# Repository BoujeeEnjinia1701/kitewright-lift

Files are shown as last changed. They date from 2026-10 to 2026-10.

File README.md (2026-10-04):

# Kitewright Lift

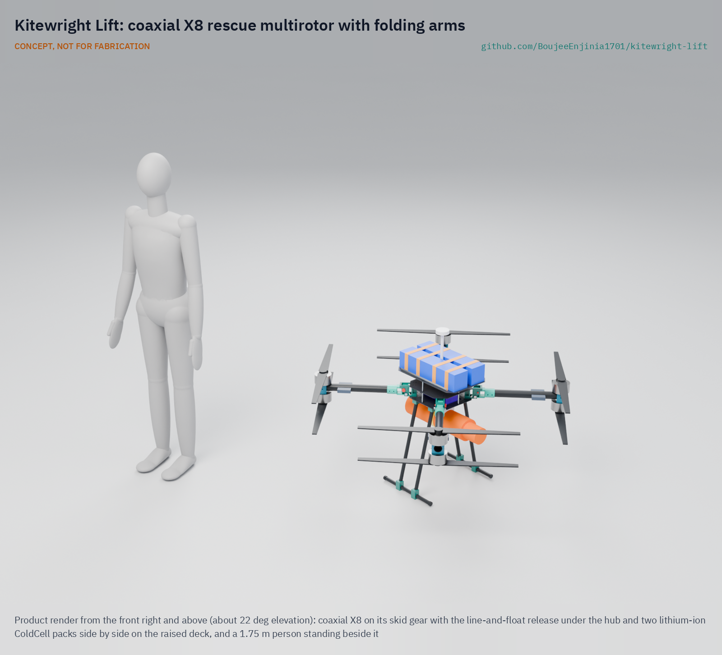
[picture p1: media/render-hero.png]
Kitewright Lift: coaxial X8 rescue multirotor with folding arms


     

**Area:** Aerial robotics · **TRL:** 3 of 9 (proof of concept on paper; design constructable) · **Value-engineering target:** USD 5,000; estimated cost of the constructable design USD 6,627 (USD 1,627 over the target) · **Difficulty:** 4 of 5

[Design precis](docs/02-concept.md) · [Requirements](docs/03-requirements.md) · [Calculations](docs/04-calcs/01-sizing.md) · [Prototype build plan](docs/05-build-plan.md) · [Design decisions](docs/06-design-decisions.md) · [General arrangement](cad/drawings/KWL-DWG-001.pdf) · [3D viewer](media/viewer.html)

A multirotor frame for the Kitewright family that hovers, lifts, winches and flies on a tether in disasters and remote terrain.

## Concept rationale

Kitewright Lift is the utility multirotor of the Kitewright family. It is a frame, motors and propellers built around the shared Kitewright Core, so the autopilot, ColdCell power bus and payload mount are the same as on every other Kitewright aircraft. What Lift adds is lift: enough thrust margin to hover with a few kilograms at altitude, a clear space under the body for payloads, and a power input for a ground tether. The same frame can search, drop a line or float, lower a small load, or stay up for hours as a lookout or radio relay over a disaster site.

The frame is sized for thin air from the start, because the family's first target is the high mountains of Kashmir and the Himalaya. Our first estimate is that at 5,000 m and -20 °C hover time falls to about 47% of sea level (estimate), so propeller and motor choices come from AltiRig bench data rather than sea-level catalogues. Keeping the take-off mass at or under 25 kg keeps Lift in the small drone classes used by the FAA and by India's Drone Rules 2021.

## Burning platform

Floods and landslides regularly cut people off. The 2022 Pakistan floods affected 33 million people ([UN News, 2022](https://news.un.org/en/story/2022/08/1125752)); the 2024 eastern Bangladesh floods affected 5.6 million, with more than 500,000 seeking shelter ([UNICEF, 2024](https://www.unicef.org/press-releases/two-million-children-risk-worst-floods-three-decades-lash-through-eastern-bangladesh)). The October 2023 South Lhonak glacial lake outburst in Sikkim left at least 35 dead and about 104 missing, destroyed 13 bridges and affected more than 60,000 people ([Mongabay India, 2023](http://india.mongabay.com/2023/10/no-early-warning-system-and-insufficient-dam-safety-turned-sikkim-flood-deadly/)). In events like these, drones already help: DJI counts more than 1,000 people rescued with drone help worldwide ([DJI, 2023](https://www.dji.com/media-center/announcements/dji-records-more-than-1000-people-rescued-by-drones-globally)).

Heavy-lift capability exists, but closed and costly. The DJI FlyCart 30 carries 30 kg with two batteries, has a winch mode for places it cannot land and a 6,000 m service ceiling ([Wikipedia, DJI FlyCart](https://en.wikipedia.org/wiki/DJI_FlyCart)); on Everest it carried 15 kg between 5,300 and 6,000 m ([DJI, 2024](https://www.dji.com/media-center/announcements/dji-completes-world-first-drone-delivery-tests-on-mount-everest-en)). The smaller DJI Matrice 350 RTK costs USD 14,814 for a 960 g payload ([Advexure](https://advexure.com/products/dji-matrice-350-rtk)). There is no open multirotor frame, documented for altitude and cold, that rescue groups can build, repair and fit with their own payloads.

## Where it could be used

### By industry

| Industry | Use |
| --- | --- |
| Flood and disaster response | Hover over stranded people, drop a float or line, and relay radio from a tether |
| Mountain rescue | Search with AvalancheScout and thermal payloads; lower small items to a casualty |
| Glacial hazard monitoring | Short-range lake and moraine survey with LakeWatch where Range cannot land |
| Remote health and logistics | Carrying light medical supplies across cut roads and rivers |
| Infrastructure inspection | Bridges, dams and hydropower intakes in steep valleys |
| Research and education | An open multirotor test bed for payload and high-altitude flight work |

### By country or region

| Country or region | Why it matters there |
| --- | --- |
| India (Sikkim and the Himalaya) | The 2023 South Lhonak outburst destroyed 13 bridges and affected more than 60,000 people ([Mongabay India, 2023](http://india.mongabay.com/2023/10/no-early-warning-system-and-insufficient-dam-safety-turned-sikkim-flood-deadly/)); a Lift at or under 25 kg sits in the Small class of India's Drone Rules 2021 ([PIB](https://static.pib.gov.in/writereaddata/specificdocs/documents/2022/jan/doc202212810701.pdf)). |
| Pakistan | The 2022 floods affected 33 million people and damaged about 3,500 km of roads and 150 bridges ([UN News, 2022](https://news.un.org/en/story/2022/08/1125752)); in the Karakoram a drone found Rick Allen alive on Broad Peak ([Explorersweb, 2018](https://explorersweb.com/rick-allen-found-alive-on-broad-peak/)). |
| Bangladesh | The 2024 eastern floods affected 5.6 million people with more than 500,000 in shelters ([UNICEF, 2024](https://www.unicef.org/press-releases/two-million-children-risk-worst-floods-three-decades-lash-through-eastern-bangladesh)). |
| Nepal | Drone delivery on Everest replaced 6 to 8 hour icefall carries with a 12 minute round trip in 2024 tests ([DJI, 2024](https://www.dji.com/media-center/announcements/dji-completes-world-first-drone-delivery-tests-on-mount-everest-en)). |
| United States | Part 107 covers drones under 55 lb (25 kg) and allows securely attached external loads ([FAA](https://www.faa.gov/uas/media/Part_107_Summary.pdf)), which is the class Lift targets. |

## What sparked the idea

In July 2018 the climber Rick Allen went missing high on Broad Peak in the Karakoram after a fall while descending. After 36 hours, Bartek Bargiel, who was filming a ski descent of K2, flew a small drone over the slope, spotted Allen alive at about 7,500 m and guided climbers to him ([Explorersweb, 2018](https://explorersweb.com/rick-allen-found-alive-on-broad-peak/)). The drone was a DJI Mavic Pro, flown far above its rated ceiling ([DroneDJ, 2018](https://dronedj.com/2018/07/16/mountaineer-rick-allen-was-feared-dead-on-broad-peak-but-a-dji-mavic-pro-drone-found-him-alive/)). Kitewright Lift is the frame that could follow such a find: hover over the spot, lower a line or supplies, and stay overhead while the rescuers climb.

## Problem

After floods, landslides and mountain accidents, rescuers need a drone that can hover over one spot, carry a few kilograms, lower a line or a float, and stay up for hours on a tether. Drones that do this are closed and cost many times what local teams can spend.

Full problem statement: [docs/01-problem.md](docs/01-problem.md)

## Concept

A coaxial X8 for the Kitewright family: four carbon arms that fold down on machined hinges, a motor above and below each arm tip with 30 inch propellers, the Kitewright Core hung under a two-plate carbon hub to the family envelope, two ColdCell packs on a raised deck above, and payloads on the Core's rail below. Lift holds each arm up against a fixed stop in flight, so a missed lock pin cannot let an arm fold. Two payloads are designed with it: a line-and-float release and a 400 V tether module for hours of hover.

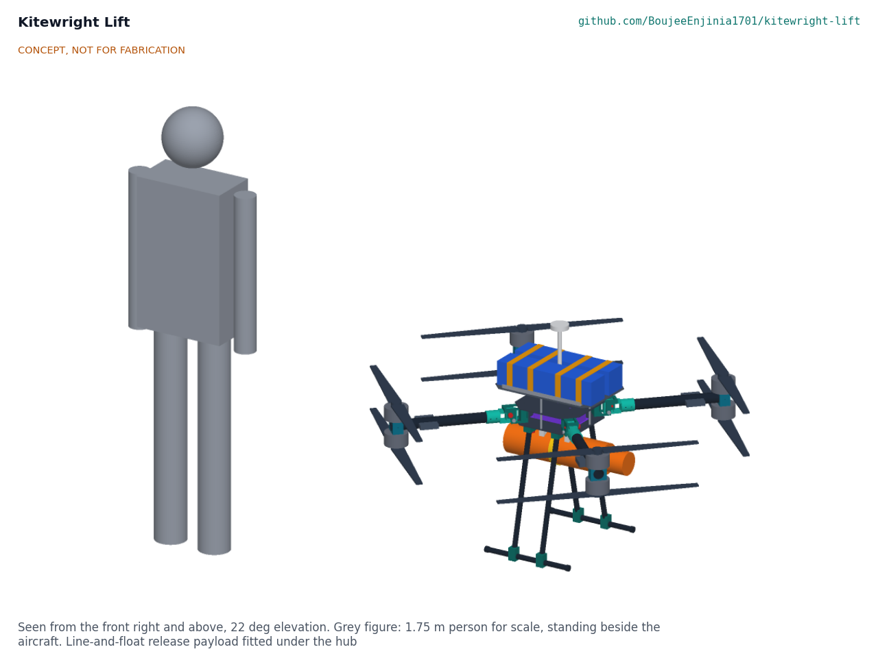
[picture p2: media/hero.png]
Kitewright Lift concept with a 1.75 m person for scale


Full design precis: [docs/02-concept.md](docs/02-concept.md) · Requirements: [docs/03-requirements.md](docs/03-requirements.md)

## Key numbers (KWL-CAL-001, estimates)

| Quantity | Value |
| --- | --- |
| Take-off mass | 21.8 kg ready to fly; 25.0 kg with the rated 3.2 kg payload |
| Thrust to weight | 2.88 at sea level; 1.84 at 5,000 m and -20 °C with 2 kg; 1.43 there with a motor out |
| Hover time (two ColdCell lithium-ion packs, 1,361 Wh) | 20.4 min at sea level with the rated payload; 14.5 min at 5,000 m with 2 kg |
| Tethered hover | 3.6 kW from a 400 V ground supply over 60 m of tether |
| Folded | 0.88 x 0.48 x 0.45 m, gear on |

No decisions are open: R4's sea-level case now reads "with the rated payload" (2026-10-04); see the [design decisions register](docs/06-design-decisions.md).

## Key components

- Carbon hub plates and battery deck
- Machined arm hinges with stop bridge, pivot bolt and lock pin
- Carbon arm tubes, root fittings and coaxial motor clamps
- Eight motors, controllers and 30 inch folding propellers
- Kitewright Core, hung under the hub to the family envelope
- Two ColdCell packs
- Skid landing gear
- Line-and-float release payload
- Tether module and ground set
- Winch module (not designed until its patent screen)

## Building the prototype

The [prototype build plan](docs/05-build-plan.md) (KWL-BLD-001) takes a capable maker through every component in build order, with a making sketch for each made part, close-ups of the joints and a picture for every assembly step. The carbon plates are CNC routed, the carbon tubes cut and drilled, and the aluminium hinge, arm and gear fittings machined; the Core and packs are built to their own designs. The hinges are proof-loaded before first flight, and the plan's safety stops cover first power, first flight, the tether and payload drops. It is a plan, not yet built.

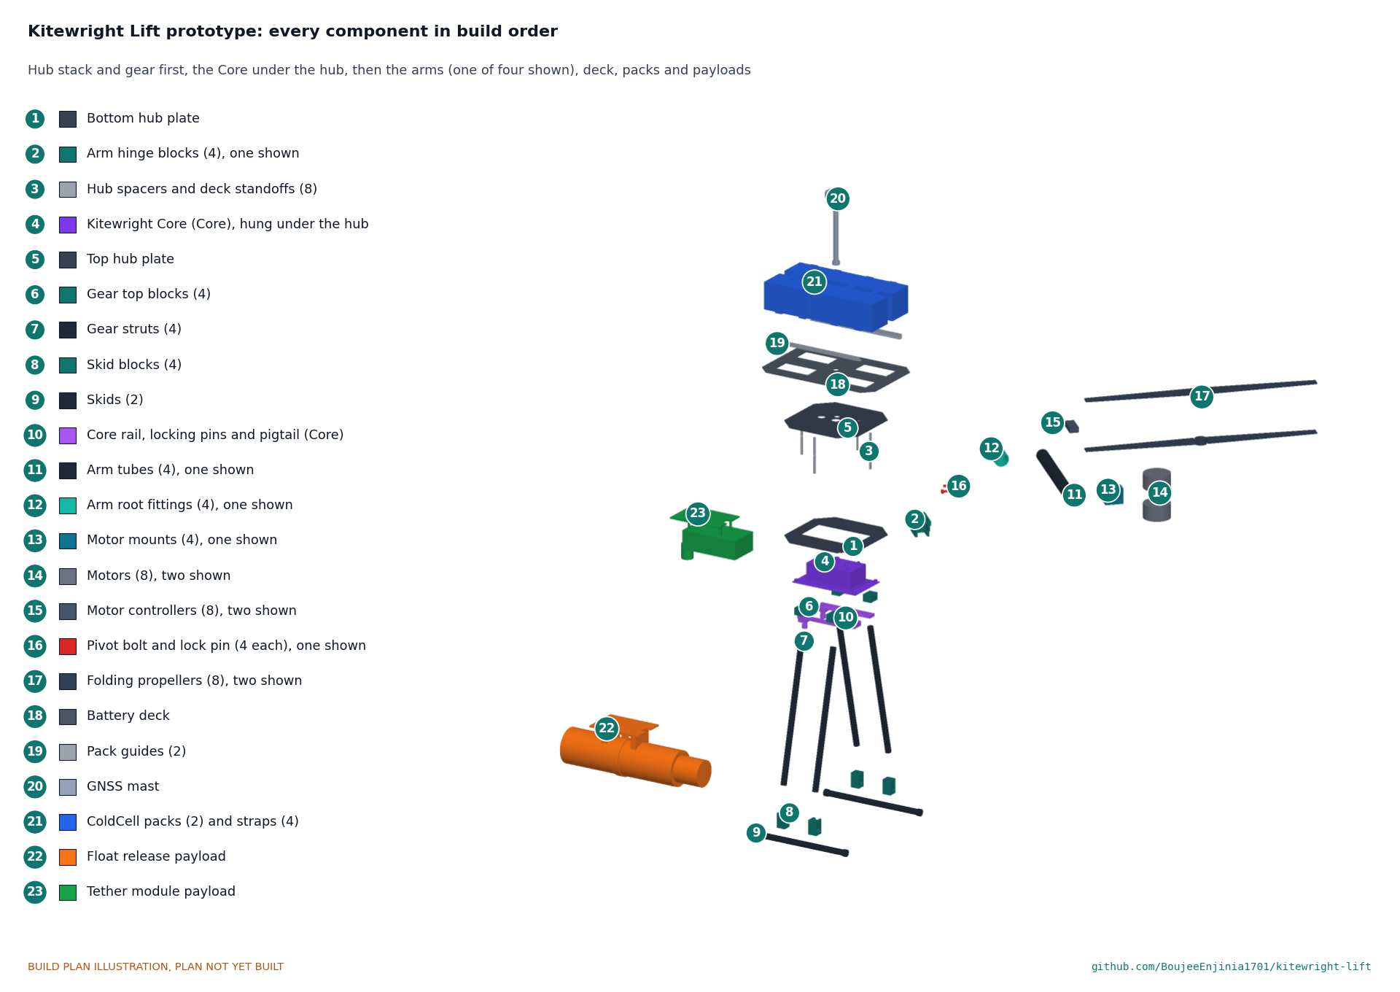
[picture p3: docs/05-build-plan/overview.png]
Every component in build order


## Safety

> Published as an open engineering reference, not certified aviation equipment.
>
> Civilian use only. No weapons, targeting or military payloads, and none will be accepted into the family.
>
> Certification and operating approvals (FAA Part 107 in the United States, EASA rules in Europe, India's DGCA Drone Rules 2021) are out of scope at this TRL and will be addressed if prototypes progress. Builders must fly only where local rules allow.
>
> Propellers can cause serious injury: arm only with every arm lock pin in and flagged and nobody within 15 m, and write pre-flight, arming and keep-out procedures before any powered test. Every arm hinge is proof-loaded before first flight.
>
> The tether carries 400 V DC: isolated, monitored ground supply with an emergency stop; nobody handles a live tether.
>
> Lithium battery packs can catch fire after a crash, over-charge or cold charging; follow ColdCell safety rules.
>
> Never carry or lift people. Suspended loads and lines must have a release that the pilot can operate at any time, and nobody stands under a suspended load. The float's line is never tied to the aircraft; drops are made from 10 m or higher.
>
> A tether can snag or conduct: route it clear of people, power lines and water currents, and fit a breakaway at the aircraft.
>
> Downwash near people in water, on snow slopes or on rooftops can knock them over or trigger slides; keep a minimum hover height set by test.
>
> Loss of link or thrust in thin air can mean a crash in remote terrain; failsafes must be set and tested at each altitude band.
>
> This design is published as an open engineering reference. It is not certified equipment. CONCEPT, NOT FOR FABRICATION.

## Repository layout

| Folder | Contents |
| --- | --- |
| `docs/` | Problem, concept, requirements, calculations and design decisions |
| `cad/src/` | build123d Python source, the source of truth for all geometry |
| `cad/step/`, `cad/stl/` | Exported models for FreeCAD, other CAD tools and printing |
| `cad/drawings/` | 2D sketches and dimensioned drawings |
| `bom/` | Bill of materials |
| `electronics/` | KiCad schematics and PCB layouts |
| `firmware/` | Microcontroller code |
| `media/` | Renders, perspectives and photos |
| `build-log/` | Dated prototyping notes |

## Documentation

Controlled documents follow the portfolio [documentation standard](.kit/STANDARDS.md). Each carries a document ID (KWL-PRC-001 for the precis), a version and a revision history. Branded PDFs are built with `python .kit/render.py` and attached to GitHub Releases when a document is tagged, for example `KWL-PRC-001/v1.0`.

## Credits

Designed by Amish Chadha at Design Molecule Labs. See [CONTRIBUTORS.md](CONTRIBUTORS.md) for roles. To cite this design, use [CITATION.cff](CITATION.cff) (GitHub shows it as "Cite this repository").

AI assistance (Claude) was used to accelerate prototype documentation and first-pass research. Design direction and all decisions are Amish Chadha's, recorded in this repository's decision records (`docs/decisions/`).

## Licenses

- **Hardware** (CAD, drawings, BOM, electronics): [CERN-OHL-S v2](LICENSE)
- **Software** (firmware, scripts, notebooks): [MIT](LICENSE-SOFTWARE)

A project of the [Design Molecule](https://designmolecule.com) lab.

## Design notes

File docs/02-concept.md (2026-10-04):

---
doc_id: KWL-PRC-001
title: Kitewright Lift design precis
project: Kitewright Lift
doc_type: Precis
version: "0.4"
status: Draft
date: '2026-10-04'
author: Amish Chadha
license: CERN-OHL-S-2.0
revisions:
- version: "0.1"
  date: '2026-09-30'
  author: Amish Chadha
  change: Initial scaffold
- version: "0.2"
  date: '2026-10-03'
  author: Amish Chadha
  change: TRL 2 and 3; coaxial X8 with down-folding arms (KWL-DDR-001), constructable design (KWL-DDR-002), first-order numbers from KWL-CAL-001, safety section
- version: "0.3"
  date: '2026-10-03'
  author: Amish Chadha
  change: Amish's decisions 34A and 35A (KWL-DDR-003); lighter fittings, lithium-ion ColdCell packs, frame-to-Core leads; numbers from KWL-CAL-001 v0.2
- version: "0.4"
  date: '2026-10-04'
  author: Amish Chadha
  change: Amish's round-3 decisions 8A, 9A and 10A (KWL-DDR-004); ColdCell's packs as drawn on a raised deck, the Core to the family envelope, payload shoes, rated payload 3.2 kg; numbers from KWL-CAL-001 v0.3
---

# Kitewright Lift design precis

A multirotor frame for the Kitewright family that hovers, lifts, winches and flies on a tether in disasters and remote terrain.

Kitewright Lift with the line-and-float release payload, a 1.75 m person for scale

*Figure 1. Kitewright Lift, flying-ready with the line-and-float release under the hub. CONCEPT, NOT FOR FABRICATION.*

## How it works

Kitewright Lift is a coaxial X8: four carbon arms on a two-plate carbon hub, each arm carrying one motor on top of its tip and one underneath, with 30 inch folding propellers turning opposite ways. If any one motor stops, its partner on the same arm keeps that corner flying, and the autopilot shares the load among the other arms, so the aircraft can still hover and land.

Each arm hinges on a machined aluminium block at a hub corner and folds down for transport. In flight the lift on the arm presses the arm's root fitting up against a stop bridge on the hinge block, so the arm cannot fold under power even if its lock pin were left out; the ball-lock pin only stops the arm drooping on the ground. Folded, with the propeller blades turned back along the arms, the aircraft measures about 0.88 x 0.48 x 0.45 m and fits the 1.2 x 0.6 x 0.5 m case of R9 with its landing gear on.

The Kitewright Core (autopilot, radios, power bus) hangs under the bottom hub plate to the family mounting envelope, its lid standing up through an opening into the hub. Two ColdCell packs, 410 x 94 x 94 mm and 4.46 kg each, sit side by side on a carbon deck raised above the upper rotors, held by guides and cam straps, with the GNSS mast between them. Under the Core, any Kitewright payload slides onto the Core's rail on its own payload shoe until it meets the front stops, two locking pins drop into the shoe, and the Core's DS-014 pigtail is plugged into the payload. Two payloads are designed here: the line-and-float release, which drops a foam float with 30 m of floating line to a person in water, and the tether module, which turns 400 V DC from a ground supply into the 51 V bus for hours of hover as a lookout or radio relay.

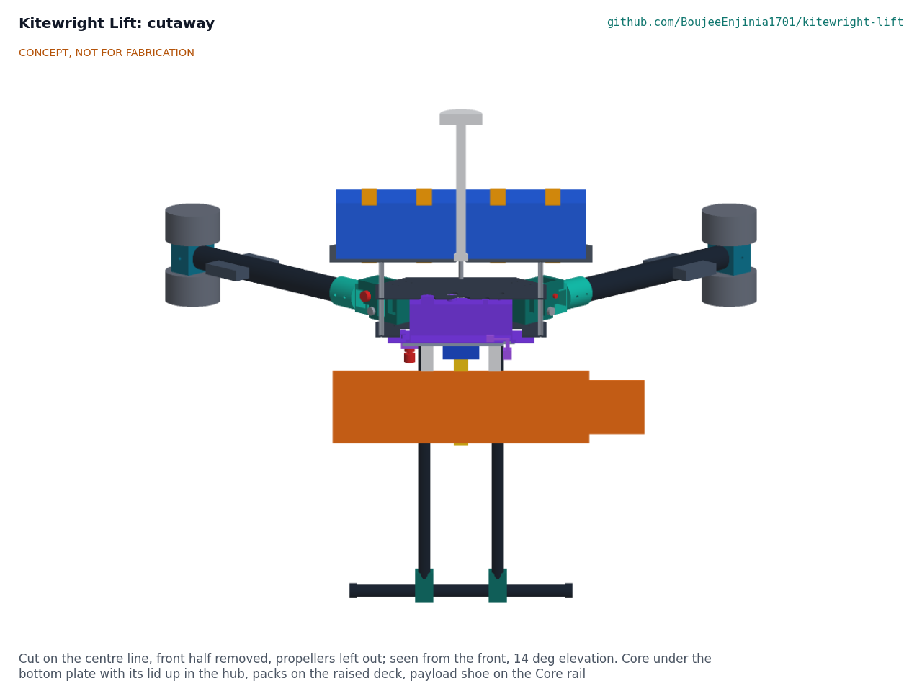
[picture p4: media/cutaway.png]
Cutaway of Kitewright Lift


*Figure 2. Cutaway on the centre line: the Core under the bottom plate with its lid up in the hub, the packs on the raised deck, the payload shoe on the Core's rail.*

## Components

| # | Component | Role |
| --- | --- | --- |
| 1 | Hub plates and spacers | Two 3 mm carbon plates 280 mm square, 60 mm apart, on the four hinge blocks and four spacers |
| 2 | Arm hinges | Machined clevis blocks with stop bridge, 8 mm pivot bolt and ball-lock pin; arms fold down |
| 3 | Arms | 40 mm carbon tubes bonded and bolted into aluminium root fittings and motor clamps |
| 4 | Motors, controllers and propellers | Eight motors of the 10 kg static thrust class, 80 A controllers on the arms, 30 x 10 folding propellers |
| 5 | Kitewright Core | Autopilot, GNSS, radios and the power bus with a tether input, unchanged from the Core design; hung under the hub to the family envelope |
| 6 | Battery deck and ColdCell packs | Two 14S3P lithium-ion heated packs (ColdCell variant for Lift) on a carbon deck above the hub, with Lift's own leads to the Core |
| 7 | Payload rail | The Core's rail, two locking pins and DS-014 pigtail under the Core plate |
| 8 | Line-and-float release | Fail-closed servo pin release, webbing sling, foam float with 30 m of line |
| 9 | Tether module and ground set | 4 kW onboard converter and breakaway; 400 V ground supply, 60 m tether, reel, insulation monitor and emergency stop |
| 10 | Landing gear | Four carbon struts and two skids, 450 mm apart, in machined blocks |
| 11 | Winch module | Not designed until its patent screen is done; the payload bay leaves room for it |

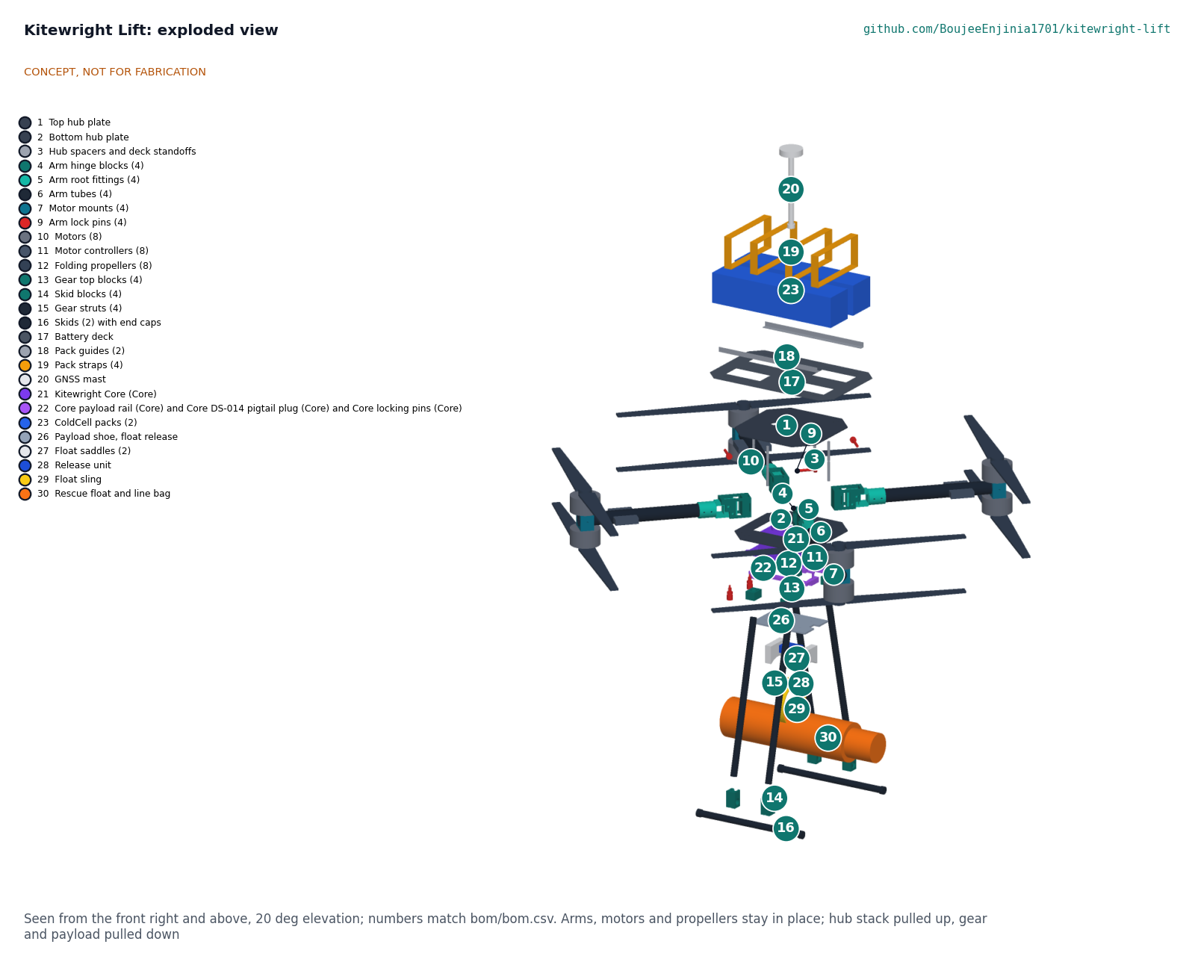
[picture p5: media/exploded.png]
Exploded view of Kitewright Lift


*Figure 3. Exploded view; numbers match `bom/bom.csv`.*

## Key design choices

All decided on 2026-10-03 under Amish's pre-approvals (KWL-DDR-001 and KWL-DDR-002):

- **Coaxial X8** rather than a flat hexa- or octocopter, for motor-out tolerance and a compact fold.
- **Arms fold down against a stop.** Lift holds each arm against a fixed bridge; the lock pin never carries flight loads.
- **Controllers on the arms**, so only two power leads per arm cross the hinge.
- **Fixed skid gear** that stays on when folded; the folded motors clear the skids and the ground.
- **One payload shoe** for every payload, to the Core's drawing KWC-DWG-106, inside the Core's 88 mm payload neck.
- **Fixed-voltage tether** (400 V DC) with an isolated onboard converter and a breakaway, clear of adaptive-voltage tether patents.
- **No winch** until its patent screen is done.

## First-order numbers

From KWL-CAL-001 (`docs/04-calcs/sizing.py`). All are estimates; nothing has been measured.

*Table 1. First-order numbers.*

| Quantity | Value | Assumptions |
| --- | --- | --- |
| Motor spacing; propellers | 1,240 mm diagonal; 30 inch, 115 mm tip gap, 170 mm coaxial gap | `cad/src/model.py` |
| Empty mass (no packs, no payload) | 12.9 kg | Made parts 5.08 kg from the model; motors 450 g, controllers 110 g, propellers 110 g, Core 0.99 kg, frame-to-Core leads 0.12 kg |
| Two ColdCell packs | 8.92 kg, 1,361 Wh | ColdCell's 14S3P lithium-ion pack as drawn, 410 x 94 x 94 mm, 4.46 kg each |
| Take-off mass with the rated payload | 24.98 kg with 3.2 kg (R1 limit 25 kg) | 21.78 kg ready to fly; float release 1.46 kg, tether module 3.13 kg |
| Hover power, sea level, rated payload | 3.2 kW | Coaxial factor 1.28, figure of merit 0.65, drive efficiency 0.80, 50 W avionics and payload |
| Hover time, sea level, rated payload | 20.4 min | 80 % of pack energy used |
| Hover time, 5,000 m and -20 C, 2 kg | 14.5 min | Air density 0.743 kg/m3; ColdCell delivers 85 % in the cold |
| Thrust to weight | 2.88 at sea level; 1.84 at 5,000 m | 10 kg per motor at full throttle, lower rotor 80 % |
| One motor out | 2.24 at sea level; 1.43 at 5,000 m | Partner motor alone on the failed arm |
| Arm load at full thrust | 177 N; 2.6 kN on the stop bridge | 30 mm from pivot to bridge |
| Tethered hover | 3.2 kW on the bus; 3.6 kW from the ground; 25 V drop and 225 W lost in the tether | 400 V, 60 m, 2 x 0.75 mm2, 95 % converter |
| Float drop | Expected miss 2.2 m from 10 m in 10 m/s wind | 2 m position hold; drift aimed off to 30 % |
| Folded size | 0.88 x 0.48 x 0.45 m | From the folded model |
| Warm-weather limit | Full hover flights to about 27 °C ambient | ColdCell's 50 °C warning, kept until measured (decision 9A) |
| Estimated cost | USD 6,627 for the aircraft; USD 3,976 for the payloads and ground equipment | `bom/bom.csv`, indicative prices |

Value-engineering target: USD 5,000. Estimated cost of the constructable design: USD 6,627 (USD 1,627 over the target).

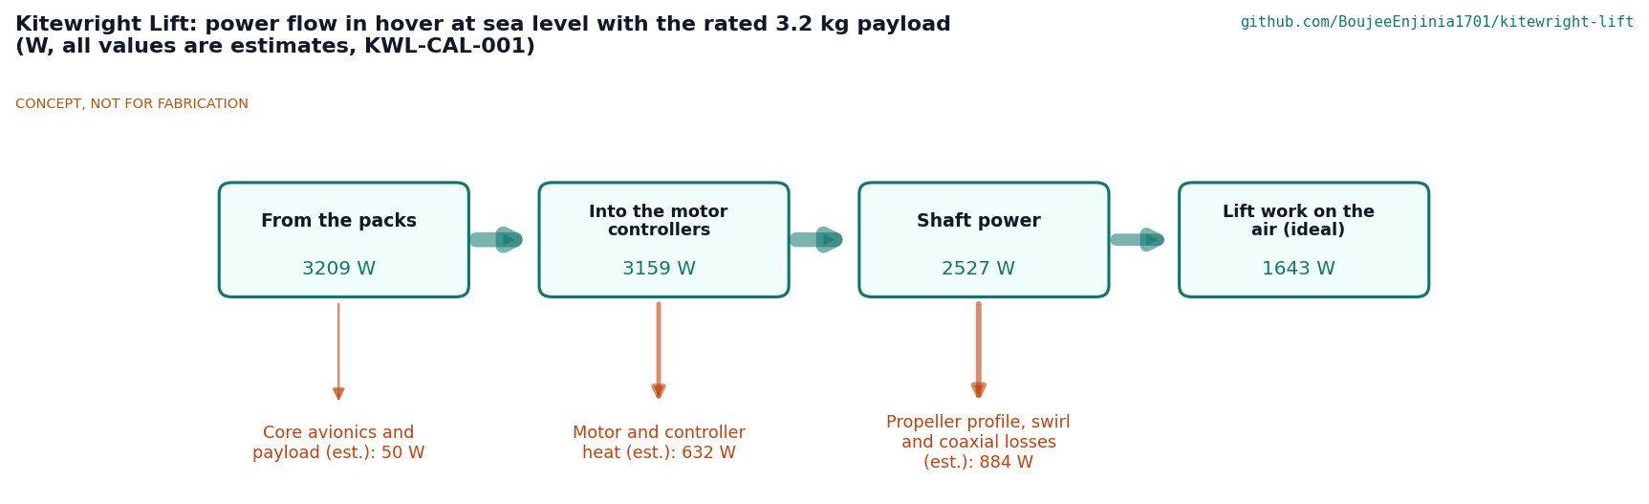
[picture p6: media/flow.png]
Power flow in hover


*Figure 4. Where the power goes in hover at sea level with 5 kg (estimates).*

## Patent design-arounds

From the preliminary patent, trademark and prior-art screen (not legal advice):

- Generic multirotor frame; no specific frame patents identified in the preliminary screen. The coaxial X8 layout and a clevis fold hinge are long-established.
- Winch not yet screened: no winch design is published until a patent screen is done.
- Tether power is a fixed-voltage supply with onboard DC-DC, not adaptive tether voltage (Elistair US11059580B2, to 2037).
- Payload mount and power bus follow the Kitewright Core design-arounds (DS-014 connector with plain rail and locking pin; external-heater ColdCell packs).

## Shared blocks

- Kitewright Core (autopilot, radios, payload mount, power bus with tether input)
- ColdCell (heated battery packs)
- AltiRig (propeller and motor data for thin air)
- AvalancheScout and LakeWatch (payloads)
- CalRig proof-load (arm hinges, tether breakaway)

## Safety

> **Safety:** Kitewright Lift is published as an open engineering reference, not certified aviation equipment, for civilian use only. No weapons, targeting or military payloads, and none will be accepted into the family.

> **Safety:** Certification and operating approvals (FAA Part 107 in the United States, EASA rules in Europe, India's DGCA Drone Rules 2021, and the civil aviation authority wherever it flies) are out of scope at this TRL and will be addressed if prototypes progress. Builders must fly only where local rules allow.

> **Safety:** Eight 30 inch propellers can cause fatal injury. Arm only with every arm lock pin in and flagged, every propeller checked, and nobody within 15 m. Write and follow pre-flight, arming and keep-out procedures before any powered test. The first power-up is done with the propellers off.

> **Safety:** The arm hinges carry the whole lift. Each hinge is proof-loaded to 1.5 times its full-thrust moment before first flight, and inspected for cracks at the pivot and stop bridge after any hard landing.

> **Safety:** Lithium-ion packs can burn fiercely after a crash, an over-charge or a cold charge. Follow ColdCell's rules for its lithium-ion variant: charging blocked below 5 °C, heater cut-outs, a fuse on every cell, charging only in the fire-resistant charging box on a non-flammable surface, and a crashed pack kept outside and watched for 24 h.

> **Safety:** The tether carries 400 V DC, a dangerous voltage. The ground supply is isolated, with an insulation monitor, residual-current protection, an emergency stop and an earth spike; the tether never crosses roads, water currents or power lines, and nobody handles it while live. The breakaway at the aircraft parts it if it snags.

> **Safety:** Never carry or lift a person. The float's line is tied to the float only, never to the aircraft. Nobody stands under a payload. Drops are made from 10 m or higher, because the downwash (about 7.4 m/s estimated at 10 m) can push a person in water under or knock someone off balance on snow or a roof.

> **Safety:** Loss of link or thrust in thin air can mean a crash in remote terrain; failsafes are set and tested at each altitude band, and the first high flights are made over ground where a crash harms nobody.

## Open questions

None for design. Amish decided the Kitewright family reconciliation on 2026-10-04 (KWL-DDR-004): ColdCell's packs as drawn, the 25 kg limit kept and the payload rated at what fits (3.2 kg). R4's sea-level case was restated the same day to "with the rated payload" as a consequence of 8A (KWL-DDR-005), so nothing is open.

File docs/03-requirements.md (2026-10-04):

---
doc_id: KWL-REQ-001
title: Kitewright Lift requirements
project: Kitewright Lift
doc_type: Requirements
version: "0.5"
status: Draft
date: '2026-10-04'
author: Amish Chadha
license: CERN-OHL-S-2.0
revisions:
- version: "0.1"
  date: '2026-09-30'
  author: Amish Chadha
  change: Initial scaffold
- version: "0.2"
  date: '2026-10-03'
  author: Amish Chadha
  change: Status of each requirement against KWL-CAL-001 for the constructable design; R11 stated as a value-engineering target
- version: "0.3"
  date: '2026-10-03'
  author: Amish Chadha
  change: Status after Amish's decisions 34A and 35A (KWL-DDR-003) against KWL-CAL-001 v0.2; R4 now met on paper; R1 and R2 still short and posed again; targets unchanged
- version: "0.4"
  date: '2026-10-04'
  author: Amish Chadha
  change: R1 and R2 restated under Amish's round-3 decision 8A (KWL-DDR-004); status of every requirement from KWL-CAL-001 v0.3 with ColdCell's packs as drawn, the Kitewright interface table and ColdCell's warm-weather limit (9A); open decision 3 closed
- version: "0.5"
  date: '2026-10-04'
  author: Amish Chadha
  change: R4's sea-level case restated to the rated payload, a consequence of Amish's round-3 decision 8A (KWL-DDR-005); open decision 4 closed
---

# Kitewright Lift requirements

Requirements for the first prototype, with the status of each against the TRL 3 calculations (KWL-CAL-001 v0.3). On 2026-10-04 Amish decided the Kitewright family reconciliation as recommended: "For round 3, I agree with all your proposed recommendations" (KWL-DDR-004). ColdCell's lithium-ion pack as drawn (410 x 94 x 94 mm, 4.46 kg) is Lift's pack; Lift keeps its 25 kg take-off limit (the US 55 lb class) and rates its payload at what fits, so **R1 and R2 are restated** below. The earlier decisions of 2026-10-03 (lighter fittings, lithium-ion packs; KWL-DDR-003) stand. "Met on paper" means the calculation shows the target is reachable; every requirement is verified by test at TRL 4 or later.

**R4 restated, 2026-10-04.** Amish Chadha, 2026-10-04: "For round 3, I agree with all your proposed recommendations". Because decision 8A rates the payload at what fits inside R1's 25 kg (about 3.3 kg), R4's sea-level case now reads "with the rated payload" in place of "with 5 kg" (open decision 4, option A; KWL-DDR-005). The design does not change.

Table 1. Requirements

| ID | Requirement | Target | Verification (TRL 3 or later) | Status at TRL 3 (KWL-CAL-001) |
| --- | --- | --- | --- | --- |
| R1 | Maximum take-off mass | 25 kg or less including the rated payload (the US 55 lb class); restated 2026-10-04, decision 8A | Weigh the fully loaded aircraft | Met on paper: 24.98 kg with the rated 3.2 kg; 21.78 kg ready to fly with two ColdCell packs of 4.46 kg |
| R2 | Payload at sea level | Rated at the payload that fits inside R1, about 3.3 kg (target); both designed payloads, the float release (about 1.6 kg) and the tether module (about 3.3 kg), must fit; restated 2026-10-04, decision 8A | Weigh each payload module; hover test with calibrated mass | Met on paper: rated payload 3.2 kg; float release 1.46 kg and tether module 3.13 kg on their payload shoes both fit; thrust to weight 2.88 |
| R3 | Payload at altitude | 2 kg at air density equivalent to 5,000 m (target) | AltiRig thrust data, then flight at a high site | Met on paper: thrust to weight 1.84 at 5,000 m and -20 C with 2 kg |
| R4 | Hover time | At least 20 min with the rated payload (R2) at sea level and 10 min with 2 kg at 5,000 m and -20 °C (targets); sea-level case restated 2026-10-04 as a consequence of decision 8A (was "with 5 kg") | Timed hover flights with logged energy use | Met on paper: 20.4 min at sea level with the rated 3.2 kg (25.0 kg) and 14.5 min at 5,000 m and -20 °C with 2 kg |
| R5 | Motor-out tolerance | Controlled descent and landing after one motor failure at rated payload | Deliberate motor cut test over a safe area | Met on paper: thrust to weight with one motor out 2.24 at sea level, 1.43 at 5,000 m; yaw control to be shown in the motor-cut test |
| R6 | Wind | Holds position within 2 m in 10 m/s steady wind (target) | Logged position hold on a windy test day | Met on paper for thrust: 18 N drag, 4.3 deg tilt; position hold depends on tuning and is shown in flight |
| R7 | Tethered endurance | At least 2 h continuous hover on fixed-voltage tether power (target) | Tethered endurance run with logged voltages and temperatures | Met on paper: 3.2 kW hover on a 4 kW converter (margin 1.25); converter and motor temperatures over 2 h to be measured |
| R8 | Float and line drop | Places a float within 3 m of a target from 10 m height (target) | Drop trials over water | Met on paper: expected miss 2.2 m in 10 m/s wind when the drift is aimed off |
| R9 | Transport | Folds to fit a case of 1.2 m by 0.6 m by 0.5 m or smaller; set up in 10 min or less (target) | Pack and timed set-up trials | Met on paper: folded 0.88 x 0.48 x 0.45 m with the gear on; set-up about 9 min |
| R10 | Operating temperature | Flies from -20 to +45 °C with ColdCell packs (target) | Cold soak then hover test | Met on paper by part ratings; pre-heat about 58 Wh from the ground supply; charging blocked below 5 °C. ColdCell's 50 °C warning (decision 9A) allows a full hover flight up to about 27 °C ambient; at +45 °C the warning comes after about 6 min, so hot days mean short flights |
| R11 | Prototype cost | USD 5,000 or less excluding payloads | Bill of materials and receipts | Value-engineering target: USD 5,000. Estimated cost of the constructable design: USD 6,627 (USD 1,627 over the target) |

## Assumptions

- Air at 5,000 m and -20 °C: 54.0 kPa and 0.743 kg/m3 (71 % of the pressure and 61 % of the density at sea level).
- Motor and propeller performance from makers' figures for the 30 inch, 100 KV class, until AltiRig measures it at 5,000 m density.
- ColdCell's lithium-ion pack for Lift (14S3P, 21700 high-power cells, 680 Wh, 410 x 94 x 94 mm and 4.46 kg, CCL-DWG-002) delivers 85 % of its rated energy at -20 °C with its heater running (ColdCell R1).
- The Kitewright Core weighs 0.99 kg with its rail and pins (Core R9) and hangs under the hub to the Kitewright interface table of 2026-10-04; Lift supplies the AS150 power harness between its packs, the Core and its arms.
- Amish, 2026-10-04 (decision 8A): "For round 3, I agree with all your proposed recommendations".
- Local rules at the test sites allow external loads and tethered flight with permission.

## Safety

> **Safety:** The requirements describe a 25 kg class aircraft with large propellers, lithium-ion packs, a 400 V tether and suspended loads. R5 (motor out) and R7 (tether) are tested only over cleared ground with the keep-out and isolation set out in the build plan's safety stops (KWL-BLD-001, section 6).

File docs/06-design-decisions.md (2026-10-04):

---
doc_id: KWL-DEC-001
title: Kitewright Lift design decisions register
project: Kitewright Lift
doc_type: Design decisions register
version: "0.4"
status: Draft
date: '2026-10-04'
author: Amish Chadha
license: CERN-OHL-S-2.0
revisions:
- version: "0.1"
  date: '2026-10-03'
  author: Amish Chadha
  change: Register opened; design decisions made under Amish's pre-approvals of 2026-10-03; two requirement decisions proposed
- version: "0.2"
  date: '2026-10-03'
  author: Amish Chadha
  change: Open decisions 1 and 2 decided by Amish (34A and 35A, KWL-DDR-003) and moved to Decisions made; new open decision 3 on R1 and R2
- version: "0.3"
  date: '2026-10-04'
  author: Amish Chadha
  change: Round-3 decisions 8A, 9A and 10A (KWL-DDR-004) recorded in Decisions made; open decision 3 closed by 8A; new open decision 4 on R4's wording
- version: "0.4"
  date: '2026-10-04'
  author: Amish Chadha
  change: Open decision 4 closed as a consequence of round-3 decision 8A (KWL-DDR-005); R4 restated to the rated payload
---

# Kitewright Lift design decisions register

Every design decision still to be made, and every decision made, in one place. Each decision is argued in full in its decision record under `docs/decisions/` or in `docs/REVIEW.md`; this register is the index Amish works from. The build plan (`docs/05-build-plan.md`) describes the design as it stands and does not list decisions.

> **Safety:** Several decisions below set Lift's safety case: the arms fold down against a fixed stop, every hinge is proof-loaded before flight, the tether runs from an isolated and monitored 400 V supply with a breakaway, the float's line is never tied to the aircraft and drops are made from 10 m or higher. Each took the conservative option; the evidence that would relax it is in KWL-DDR-001, Table 1.

## Open decisions

None. Open decision 3 (R1 and R2) was overtaken by Amish's round-3 decision 8A of 2026-10-04 (KWL-DDR-004), and open decision 4 (R4's wording at sea level) was closed on 2026-10-04 as a consequence of 8A, option A (KWL-DDR-005). Nothing in carrying them out needs Amish.

## To confirm when parts are bought

| # | What to confirm | Why it matters | Source |
| --- | --- | --- | --- |
| 1 | The motors' full-throttle thrust with a 30 x 10 propeller at 51 V (about 10 kg), their mass (about 450 g) and their base hole pattern (35 mm circle assumed) | Sets the thrust margins (R3, R5) and the clamp's tapped holes | KWL-CAL-001, D; KWL-DWG-107 |
| 2 | The lithium-ion 21700 cells' continuous current rating (45 A assumed), capacity (4.5 Ah) and mass (70 g), and the pack's energy at -20 °C with its heater running (85 % assumed) | Hover draws about 11 A per cell and a climb 16 A; R4 has 0.1 min of margin at sea level | KWL-CAL-001, C; KWL-DDR-003 |
| 3 | The controllers run on the 14S lithium-ion bus (58.8 V full) with margin and report telemetry to the Core | Bus voltage and failure detection for R5 | KWL-CAL-001, D |
| 4 | The propellers' hub height and blade fold: both blades turn back along the arm when folded | Folded size (R9) and blade clearance to the gear (14 mm) | KWL-CAL-001, I |
| 5 | The ball-lock pins' grip length fits the 46 mm hinge block, and the shoulder bolts' shoulder is 8.00 mm | A pin too short will not lock; a loose pivot lets the arm rattle | KWL-DWG-104 |
| 6 | The DC-DC converter's input range covers 400 V less the 23 V tether drop, its output is adjustable to the bus float voltage, and it is rated at 4 kW at +45 °C | R7 for two hours in heat | KWL-CAL-001, G |
| 7 | The breakaway connector's pull-release force (about 200 N) and voltage rating (600 V) | It must part before the tether pulls the aircraft over | KWL-DDR-001, item 5 |
| 8 | The release unit stays closed when unpowered and on a failed signal | A release that opens on a fault drops the float unasked | KWL-DDR-001, item 7 |
| 9 | The Core stack fits 150 x 100 x 40 mm on four 10 mm dampers and the payload rails are 112 mm apart with 8 mm slots | Lift's plates are drilled for these (Cross-repo actions) | KWL-DDR-001, item 8 |
| 10 | Each lithium-ion ColdCell pack fits 126 x 232 x 85 mm and weighs about 3.56 kg | Deck, guides and straps are sized for this; every 0.1 kg counts against R1 | KWL-DDR-003 |
| 11 | The frame-to-Core leads: 8 AWG wire and AS150 halves weigh about 0.12 kg in all and fit the Core's pads, strain-relief bar and grommets | Mass against R1; the Core no longer carries the leads (Core decision 33B) | KWL-DDR-003 |

## Value engineering

Value-engineering target: USD 5,000 (a hypothetical control target, not a limit). Estimated cost of the constructable design: USD 6,335 (USD 1,335 over the target), excluding the payloads and ground set (USD 3,716). Decisions 34A and 35A and Core decision 33B added USD 596 (packs USD 416, pockets USD 120, leads USD 60). Main cost drivers and savings worth trying:

- Motors (USD 1,480), the two lithium-ion ColdCell packs (USD 1,256), the Core stack and payload mount (USD 1,050), the controllers (USD 680) and the propellers (USD 440) are 77 % of the aircraft.
- The machined fittings (USD 776 for 20 parts) are the largest made cost.
- Savings worth trying: integrated motor-and-controller units of the agricultural-drone class bought as a set of eight; one batch order of all machined parts from one CNC service; carbon plates nested on one sheet; motors and propellers bought as a matched set.
- The tether ground set (USD 2,390) is the largest payload cost; a shared ground supply across the Kitewright family would spread it.

## Decisions made

The pre-approvals: Amish, 2026-10-03: "start with the first 14 repos from the list of 29 projects. I pre-approve the batch runs along with any recommendations you come up with. I also accept any cost overruns or variations from the assumed scope cost." and, for this batch, "Proceed with the remaining 15 scaffolds".

| Date | Decision | Decided by | Record |
| --- | --- | --- | --- |
| 2026-10-03 | Coaxial X8 layout: four arms, a motor above and below each tip | Amish, under both pre-approvals quoted above | KWL-DDR-001, item 1 |
| 2026-10-03 | Arms fold down; lift held by a stop bridge; lock pin against droop only | Amish, under both pre-approvals quoted above | KWL-DDR-001, item 2 |
| 2026-10-03 | 30 inch folding propellers, 100 KV class motors, controllers on the arms | Amish, under both pre-approvals quoted above | KWL-DDR-001, item 3 |
| 2026-10-03 | Two ColdCell LiFePO4 16S2P packs as the baseline (superseded by decision 35A below) | Amish, under both pre-approvals quoted above | KWL-DDR-001, item 4 |
| 2026-10-03 | Fixed 400 V DC tether, 60 m, 4 kW onboard converter, breakaway, monitored isolated ground supply, 50 m highest hover | Amish, under both pre-approvals quoted above | KWL-DDR-001, item 5 |
| 2026-10-03 | No winch designed until its patent screen | Amish, under both pre-approvals quoted above | KWL-DDR-001, item 6 |
| 2026-10-03 | Fail-closed servo pin release; float line never tied to the aircraft; drops from 10 m or higher | Amish, under both pre-approvals quoted above | KWL-DDR-001, item 7 |
| 2026-10-03 | Core payload mount under the bottom plate; one standard payload plate | Amish, under both pre-approvals quoted above | KWL-DDR-001, item 8 |
| 2026-10-03 | Fixed skid gear, 450 mm apart, hub 500 mm up | Amish, under both pre-approvals quoted above | KWL-DDR-001, item 9 |
| 2026-10-03 | Keep-out 15 m when armed; no hover over people on snow slopes or roofs | Amish, under both pre-approvals quoted above | KWL-DDR-001, item 10 |
| 2026-10-03 | First co-design candidate to approach: the Himalayan Rescue Association, Nepal (not agreed) | Amish, under both pre-approvals quoted above | KWL-DDR-001, item 11 |
| 2026-10-03 | First high-altitude test region to approach: Khumbu, Nepal, after sea-level trials (not agreed) | Amish, under both pre-approvals quoted above | KWL-DDR-001, item 12 |
| 2026-10-03 | AltiRig for thrust at 5,000 m density; CalRig for hinge proof loads at 1.5 times full thrust and the breakaway pull | Amish, under both pre-approvals quoted above | KWL-DDR-001, item 13 |
| 2026-10-03 | `budget_usd` kept at 5,000 as a value-engineering target | Amish: "I also accept any cost overruns or variations from the assumed scope cost." | KWL-DDR-001, item 14 |
| 2026-10-03 | Design for construction: the fourteen changes of KWL-DDR-002 | Amish, under both pre-approvals quoted above | KWL-DDR-002 |
| 2026-10-03 | Appearance model additions for renders: mannequin beside the aircraft; one arm hinge with short pieces of the hub plates for the detail view | Amish, under both pre-approvals quoted above | `docs/REVIEW.md`, TRL 3 |
| 2026-10-03 | Open decision 1, R1 and R2 (item 34A): pocket the hinge blocks, root fittings and motor clamps deeper; done in the model as side pockets, windows and cut-away corners, and a 40 mm clamp; 0.78 kg saved (1.04 kg estimated) | Amish: "i agree with all the 46 recommendations you provided. please proceed." | KWL-DDR-003 |
| 2026-10-03 | Open decision 2, R4 (item 35A): a lithium-ion ColdCell variant for Lift, 14S3P of 21700 high-power cells, about 680 Wh and 3.56 kg per pack, with ColdCell's charge blocking below 5 °C, heater cut-outs, cell fuses and charging box | Amish: "i agree with all the 46 recommendations you provided. please proceed." | KWL-DDR-003 |
| 2026-10-03 | Lift supplies its own power leads from the frame to the Core (8 AWG, four AS150 halves), following Kitewright Core decision 33B | Amish: "i agree with all the 46 recommendations you provided. please proceed." | KWL-DDR-003 |
| 2026-10-04 | Open decision 3 closed by round-3 decision 8A: ColdCell's lithium-ion pack as drawn (410 x 94 x 94 mm, 4.46 kg, 680 Wh) is Lift's pack; the battery deck re-sized (430 x 280 x 2 mm with four windows, on 60 mm standoffs so it sits above the upper rotors) and mass, hover time and thrust margins re-run; the 25 kg take-off limit (US 55 lb class) kept; R1 and R2 restated and the payload rated at what fits, 3.2 kg; the float release (1.46 kg) and tether module (3.13 kg) both fit | Amish: "For round 3, I agree with all your proposed recommendations" | KWL-DDR-004 |
| 2026-10-04 | Round-3 decision 9A (ColdCell): the 50 °C firmware warning stays for the lithium-ion pack until a TRL 4 measurement supports relaxing it; full-length hover flights to about 27 °C ambient (R10) | Amish, as above | KWL-DDR-004; CCL-DDR-004 |
| 2026-10-04 | Round-3 decision 10A: AS150 plugs everywhere; the Kitewright Core hung under the bottom hub plate to the family envelope (four M4 on 220 x 130 mm, 200 x 112 mm opening, holes in the top plate over the lid's boss, SMA bulkheads and switch; GNSS on the deck mast and antennas on extension leads); payloads on 184 x 128 x 5 mm payload shoes inside the 88 mm neck; the Kitewright interface table in `docs/REVIEW.md` | Amish, as above | KWL-DDR-004 |
| 2026-10-04 | Open decision 4 closed as a consequence of round-3 decision 8A (option A): R4's sea-level case restated to "at least 20 min with the rated payload (R2) at sea level" (was "with 5 kg"); 20.4 min with 3.2 kg, met on paper; no design change | Amish: "For round 3, I agree with all your proposed recommendations" | KWL-DDR-005 |

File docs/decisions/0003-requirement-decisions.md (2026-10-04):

---
doc_id: KWL-DDR-003
title: Kitewright Lift requirement decisions of 2026-10-03
project: Kitewright Lift
doc_type: Design decision record
version: "0.1"
status: Draft
date: '2026-10-03'
author: Amish Chadha
license: CERN-OHL-S-2.0
revisions:
- version: "0.1"
  date: '2026-10-03'
  author: Amish Chadha
  change: Amish's decisions 34A (lighter fittings) and 35A (lithium-ion ColdCell packs) carried out, with Kitewright Core decision 33B (frame-to-Core power leads)
---

# 0003: Requirement decisions of 2026-10-03

- **Date:** 2026-10-03
- **Status:** accepted

## Context

The TRL 3 calculations (KWL-CAL-001 v0.1) left two results short of the requirements, posed to Amish as open decisions 1 and 2 in `docs/REVIEW.md`:

- R1 and R2: 25.5 kg with a 5 kg payload, 0.5 kg over the 25 kg limit; the machined fittings were simple pocketed blocks.
- R4: 8.9 min of hover at sea level with 5 kg and 7.1 min at 5,000 m and -20 °C with 2 kg on the LiFePO4 ColdCell packs.

In parallel, Kitewright Core decision 33B moves the pack and frame power leads and their AS150 plugs out of the Core and into each frame's harness, so Lift now supplies its own leads from the frame to the Core.

Amish Chadha, 2026-10-03: "i agree with all the 46 recommendations you provided. please proceed."

## Options considered

As posed in `docs/REVIEW.md` (TRL 3, "Decisions for Amish"):

- Decision 1 (item 34): A, pocket the hinge blocks, root fittings and motor clamps deeper (estimated 1.04 kg less, about USD 120); B, rate the sea-level payload at 4.5 kg.
- Decision 2 (item 35): A, a lithium-ion ColdCell variant for Lift (14S3P of 21700 high-power cells) with 1A; B, LiFePO4 with a third cell in parallel; C, keep the LiFePO4 packs and use the tether for long hovers.

## Decision

Option A on both, as recommended.

*Table 1. Changes made.*

| # | Change | Where | Result |
| --- | --- | --- | --- |
| 34A-1 | Hinge blocks: side pockets 19 x 11 mm in the bolting end, an 18 x 46 mm window through both cheeks, the cheeks cut away below the pivot outboard and under the stop bridge to a 15 mm top rail; 4 to 5 mm walls round every hole | `cad/src/model.py` (`hinge_block_local`); KWL-DWG-104 Rev P2 | 0.29 to 0.19 kg each |
| 34A-2 | Root fittings: 12.5 mm side pockets leaving a 5 mm web and 5 mm bosses round the pivot and lock holes; window 22 x 28 mm (was 22 x 24) | `tongue_local`; KWL-DWG-105 Rev P2 | 0.29 to 0.24 kg each |
| 34A-3 | Motor clamps shortened from 50 to 40 mm along the arm; arm tubes cut to 405 mm (was 410) so the tube ends flush with the clamp | `PARAMS["mount"]`, `PARAMS["tube_r"]`; KWL-DWG-106 and 107 Rev P2 | 0.24 to 0.19 kg each |
| 35A | ColdCell lithium-ion packs for Lift: 14S3P of 21700 high-power cells (4.5 Ah, 45 A), 50.4 V nominal, about 680 Wh and 3.56 kg each, in the same 126 x 232 x 85 mm envelope; ColdCell's charge blocking below 5 °C, heater cut-outs, cell-level fuse and fire-resistant charging box | BOM line 23; KWL-CAL-001; build plan section 3.17 | 1,361 Wh in two packs, against 614 Wh |
| 33B (Core) | Frame-to-Core power leads: 8 AWG silicone wire and four AS150 anti-spark halves, soldered to the Core's pads; the Core is now about 0.99 kg | BOM line 24 (and 21 mass); build plan section 3.5 and step 13 | About 0.12 kg and USD 60 added to Lift |

The highest stress in the lightened fittings at full thrust is in the 15 mm top rail under the stop bridge; every figure is under a third of the 6061-T6 yield (KWL-CAL-001, F). The stop bridge itself is unchanged.

## Consequences

*Table 2. Results against the requirements (KWL-CAL-001 v0.2).*

| Requirement | Before | After | Status |
| --- | --- | --- | --- |
| R1, take-off mass with 5 kg | 25.5 kg | 25.2 kg | Not met, by about 0.2 kg |
| R2, payload inside R1 | 4.5 kg | 4.8 kg | At risk |
| R4, hover time | 8.9 and 7.1 min | 20.1 min at sea level with 5 kg; 16.1 min at 5,000 m and -20 °C with 2 kg | Met on paper |
| R11, cost | USD 5,739 | USD 6,335 | USD 1,335 over the value-engineering target |

- The modelled fittings save 0.79 kg, not the 1.04 kg estimated when the decision was posed: the root fittings' collar is already thin-walled and their tongues need full-width bosses at both holes, so they give up about 0.05 kg each rather than 0.10. With the lithium-ion packs (0.44 kg heavier than the LiFePO4 pair) and the frame-to-Core leads (0.12 kg), the aircraft weighs 25.2 kg with a 5 kg payload. This is posed to Amish as a new open decision in `docs/REVIEW.md` and the register.
- R4 is met at both conditions with margin; hover current is about 11 A per cell against a 45 A rating.
- Lithium-ion cells carry more fire energy than LiFePO4: ColdCell's conservative rules apply in full (charge blocking below 5 °C, heater cut-outs, a cell-level fuse and the fire-resistant charging box), and the build plan's safety stops say so.
- Cross-repo: ColdCell adds and confirms the lithium-ion variant (cells, envelope, mass, energy at -20 °C); Kitewright Core's leads now come from Lift's harness.

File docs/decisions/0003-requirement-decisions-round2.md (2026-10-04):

---
doc_id: KWL-DDR-003
title: Kitewright Lift requirement decisions, round 2
project: Kitewright Lift
doc_type: Design decision record
version: "0.1"
status: Draft
date: '2026-10-03'
author: Amish Chadha
license: CERN-OHL-S-2.0
revisions:
- version: "0.1"
  date: '2026-10-03'
  author: Amish Chadha
  change: Decisions 1 and 2 (R1 and R2, R4) decided by Amish as recommended, option A each, and Kitewright Core decision O1 option B carried into Lift's harness
---

# 0003: Requirement decisions, round 2

- **Date:** 2026-10-03
- **Status:** Decided. Decided by Amish Chadha on 2026-10-03: "i approve all of the 47 recommendations provided by you. Execute them." Each decision below is the recommended option, exactly as worded, including its conditions.

## Context

The TRL 3 calculations (KWL-CAL-001 v0.1) left R1 not met and R2 at risk (25.5 kg with a 5 kg payload) and R4 not met (8.9 min at sea level, 7.1 min at 5,000 m). Both were posed to Amish in `docs/REVIEW.md` and in the design decisions register (KWL-DEC-001). In the same round Amish decided Kitewright Core's O1 option B (KWC-DDR-003), which moves the Core's pack and frame leads and their AS150 plugs into each frame's harness. This record states what was chosen, what it changed when carried into the model, and the conditions.

## Options considered

*Table 1. Decisions as posed (global numbers 18 and 19).*

| # | Requirement | Option A | Option B | Option C |
| --- | --- | --- | --- | --- |
| 1 (18) | R1 and R2, take-off mass with 5 kg | Pocket the hinge blocks, root fittings and motor clamps deeper: 24.4 kg with 5 kg, both met, hover +0.6 min, about USD 120, 1.04 kg less | Rate the sea-level payload at 4.5 kg: R1 met, R2 not met by 0.5 kg | |
| 2 (19) | R4, hover time | A lithium-ion ColdCell variant, 14S3P of 21700 high-power cells, with decision 1 A: 20.5 and 16.5 min, met, 24.9 kg, about USD 416 more, 0.44 kg more than LiFePO4 (net 0.6 kg less with 1 A) | LiFePO4 16S3P: 13.8 min with only 1.7 kg payload, 9.0 min at 5,000 m, not met, USD 130, 2.9 kg more | Keep LiFePO4 16S2P and use the tether: not met |

## Decision

*Table 2. Decisions, effect and conditions.*

| # | Requirement | Option chosen | Effect, as carried into the model | Condition |
| --- | --- | --- | --- | --- |
| 1 (18) | R1 and R2 | **A**: pocket the hinge blocks, root fittings and motor clamps deeper (side pockets leaving 4 to 5 mm walls and webs round the holes) | Pockets drawn with 4.5 mm walls and webs round every hole, boss and face; the bridge, pivot and lock-pin bosses untouched. Saving **0.41 kg** (hinge blocks 0.20, root fittings 0.13, clamps 0.08), not the 1.04 kg estimated: the fittings do not hold that much removable metal under the stated wall rule. USD 120 more machining (lines 4, 5, 7) | "Stresses stay under a third of yield": the load-carrying sections (bridge, pivot and lock bosses, cheeks at the pins) are unchanged, so the stresses of KWL-CAL-001 F stand; the 4.5 mm cheek walls beside the pockets are covered by the hinge proof load at TRL 4 |
| 2 (19) | R4 | **A**: the lithium-ion ColdCell variant, 14S3P of 21700 high-power cells, with decision 1 A | ColdCell now carries the variant (CCL-DDR-003): 680 Wh, 3.84 kg, 378 x 90 x 86 mm, USD 662 a pack. Hover 18.9 min at sea level with 5 kg and 15.0 min at 5,000 m with 2 kg (was 8.9 and 7.1). The deck grows to 290 x 430 mm and the guides shorten to 210 mm for the long packs | The decision's condition "it needs ColdCell to accept a lithium-ion variant": accepted in ColdCell (CCL-DDR-003) with its full protections. Motors, controllers and the Core bus stay unchanged (14S, 42 to 58.8 V, inside the Core's 18 to 60 V) |
| Core O1 (17) | Kitewright Core R9 | Kitewright Core's **B**: the pack and frame leads and AS150 plugs move to each frame's harness | Lift's harness (line 24) gains 2 m of 8 AWG wire and four AS150 halves, two pack inputs and two frame outputs, soldered to the Core's board pads and tied to its strain-relief bar: USD 60, 0.12 kg. The Core allowance stays 1.0 kg (Core estimate 0.996 kg without leads) | "The lead lengths were frame-specific anyway": Lift's leads are cut to its deck and hub |

**Outcome against the requirements.** Taken together, the decisions do not deliver the 24.9 kg they were posed with: the aircraft is estimated at **26.3 kg with a 5 kg payload**, so R1 is still not met and R2 is at risk (3.7 kg of payload inside 25 kg). R4 is met at 5,000 m (15.0 min) but missed by 1.1 min at sea level with 5 kg (18.9 min). The causes are set out in KWL-CAL-001 v0.2, Table 5: the smaller pocket saving (0.63 kg), ColdCell's heavier pack (0.57 kg for two), the larger deck (0.12 kg) and the Core leads (0.12 kg). The decisions are carried out as approved; the shortfall is posed to Amish as a new question (KWL-DEC-001, open decision 3), not decided here.

## Consequences

- `cad/src/model.py`: pocket geometry in the hinge blocks, root fittings and motor clamps (`pockets`, `web` parameters); pack envelope 90.4 x 378 x 85.8 mm; deck 290 x 430 mm; guides at X -95, 0 and 95 mm. Constructability checks pass in all three states.
- KWL-CAL-001 v0.2; `bom/bom.csv` lines 4, 5, 7, 17, 18, 21, 23 and 24; KWL-DWG-001 Rev P3 and KWL-DWG-002 Rev P2; making sketches, joints and steps regenerated; build plan KWL-BLD-001 v0.2.
- New questions (KWL-DEC-001, proposed, awaiting Amish): 3, take-off mass after round 2; 4, hot-weather operation with the lithium-ion packs (with ColdCell open decision 6).

> **Safety:** Lift now carries two 680 Wh lithium-ion packs, 1.36 kWh in all, about twice the energy of the LiFePO4 packs, in cells whose failure can vent flammable gas and spread from cell to cell. A crash, a puncture or a cold charge is more dangerous than before: after any hard landing the packs come out and are watched outside for 24 hours (build plan safety stop 7), they are charged and stored in a fire-resistant container, never unattended, and they cannot travel with air passengers. ColdCell's charge lockout, heater cut-offs and new 60 C discharge cut-out apply in full. The deeper pockets do not touch the stop bridge or the pin bosses that carry the arm's lift; every hinge is still proof-loaded at 1.5 times its full-thrust moment before first flight.

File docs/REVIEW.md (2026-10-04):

# Review note: Kitewright Lift

## 2026-10-04: Amish's round-3 decisions carried out

Amish Chadha (owner) on 2026-10-04: "For round 3, I agree with all your proposed recommendations". For Lift that is the Kitewright family reconciliation: 8A (ColdCell's pack as drawn is the Lift pack), 9A (ColdCell's 50 °C warning and the warm-weather limit) and 10A (AS150 everywhere, one Core mounting envelope). Kitewright Core, Kitewright Range, ColdCell, AvalancheScout and LakeWatch were brought to the same table in the same session. Recorded in `docs/decisions/0004-family-reconciliation.md` (KWL-DDR-004) and the register (`docs/06-design-decisions.md` v0.3). Nothing was committed or pushed.

### Changes made

- **8A, battery deck re-sized for two ColdCell packs of 410 x 94 x 94 mm and 4.46 kg** (`cad/src/model.py`): packs side by side in Y with a 30 mm gap for the GNSS mast; deck 430 x 280 x 2 mm carbon (was 330 x 290 x 3) with four 120 x 60 mm windows; on 60 mm standoffs (were 25) so its underside is 9 mm above the upper blades, with the deck's corner cuts 12.7 mm and the pack corners 22.7 mm outside the upper discs in plan; guides 15 x 15 x 1.5 angle, 340 mm; four 900 mm straps round both packs. Deck check added: 19 MPa at mid-span and 27 MPa through the windows at a 3 g landing.
- **8A, R1 and R2 restated** (`docs/03-requirements.md` v0.4, Amish quoted): 25 kg take-off limit kept (US 55 lb class); payload rated at what fits; both designed payloads must fit.
- **9A:** ColdCell's 50 °C warning kept; warm-weather limit (about 27 °C ambient for a full hover flight; at 45 °C the warning after about 6 min) in the build plan's operating note (section 3.17) and in R10.
- **10A, the Core to the family envelope** (new `cad/src/core_envelope.py`, the same file as Range's): the Core plate hangs under the bottom hub plate on its 8 mm spacers (M4 on 220 x 130 mm), its lid up through a 200 x 112 mm opening that replaces the damper, rail and socket holes; the top plate has holes over the lid's mast boss (26 mm), SMA bulkheads (12 mm) and switch (20 mm); the Core's GNSS receiver goes on Lift's deck mast and its antennas on SMA extension leads to the gear struts. Payloads hang from 184 x 128 x 5 mm payload shoes (KWC-DWG-106) inside the Core's 88 mm neck: float saddles 80 mm wide and 55 mm tall; the tether converter on four 34 mm posts, 20 mm ahead of the pin knobs. AS150 on every pack and bus lead. New model checks: payload parts outside the neck zone, the Core's parts against the hub.
- Constructability checks pass in all three states (flying with the float release, flying with the tether module, folded): no overlaps, nothing out of contact. STEP and STL regenerated.
- **BOM** (`bom/bom.csv`, 39 lines): lines 1, 2, 3, 17, 18, 19, 21, 22, 23, 24, 26, 27 and 31 changed, each with a price basis; new line 39, ColdCell's ground equipment (USD 255, not in R11).
- Documents: `docs/04-calcs/01-sizing.md` v0.3 with `sizing.py` and `results.csv`, `docs/05-build-plan.md` v0.3, `docs/02-concept.md` v0.4, `docs/03-requirements.md` v0.4, `docs/06-design-decisions.md` v0.3, `README.md`.

### New result per requirement (KWL-CAL-001 v0.3, estimates)

| ID | Before (v0.2) | Now | Target |
| --- | --- | --- | --- |
| R1 | 25.2 kg with 5 kg, not met | 24.98 kg with the rated 3.2 kg; 21.78 kg ready to fly: met on paper as restated | 25 kg or less with the rated payload |
| R2 | 4.77 kg inside R1, at risk | Rated 3.2 kg; float release 1.46 kg and tether module 3.13 kg (on payload shoes) both fit; met on paper as restated | About 3.3 kg, both payloads fit |
| R3 | Thrust to weight 1.97 | 1.84 at 5,000 m with 2 kg: met on paper | 2 kg at 5,000 m |
| R4 | 20.1 and 16.1 min | 20.4 min at sea level with the rated payload, 14.5 min at 5,000 m with 2 kg: met on paper (R4 restated to the rated payload, open decision 4 closed) | 20 and 10 min |
| R5 | 2.22 and 1.53 | 2.24 and 1.43: met on paper | Controlled descent |
| R7 | Converter margin 1.37 | 1.25 at 3.2 kW: met on paper | 2 h on the tether |
| R9 | 0.84 x 0.48 x 0.45 m | 0.88 x 0.48 x 0.45 m: met on paper | 1.2 x 0.6 x 0.5 m case |
| R10 | Part ratings | Part ratings; full hover flights to about 27 °C ambient (9A) | -20 to +45 °C |
| R11 | USD 6,335 | Value-engineering target: USD 5,000. Estimated cost of the constructable design: USD 6,627 (USD 1,627 over the target) | Reported against the target |

R6 and R8 are unchanged and met on paper. Mass: ready to fly 1.55 kg heavier (packs +1.80 kg; deck, guides and bottom plate opening -0.29 kg; standoffs and antenna leads +0.04 kg). Cost: ColdCell's packs USD 268 more (USD 762 each against USD 628 assumed), deck USD 5, straps USD 4, antenna leads USD 15. `budget_usd` unchanged.

### Kitewright interface table

The same table stands in the review notes of Kitewright Core, Kitewright Lift, Kitewright Range, ColdCell, AvalancheScout and LakeWatch (Amish's decision 10A, 2026-10-04). The Core's drawings are the reference for the mounting envelope.

| Interface | Family figure | Source |
| --- | --- | --- |
| Power connector | AS150 on every pack lead and on each frame's power harness (two pack inputs, two frame outputs, opposite genders); no XT60 or XT90 on the bus | Decision 10A; KWC-DDR-001, D3 |
| Core mounting envelope and hole pattern | Core plate 240 x 150 x 2 mm hung under the frame's lower deck on four 12 mm OD x 8 mm corner spacers; four M4 holes on a 220 x 130 mm pattern; a 200 x 112 mm opening in the deck for the lid; lid 168 x 92 mm, its top 55 mm above the deck's underside (GNSS mast boss 69 mm); where a frame has no 240 mm clear above the lid, the antennas and GNSS receiver go to frame positions on extension cables; rail, pin blocks and pin knobs to 47 mm below the plate top; payload shoe 184 x 128 x 5 mm, payload neck 88 mm wide from the shoe to 30 mm below the rail lips | KWC-DWG-001 Rev P2, KWC-DWG-106 |
| Bus voltage | 18 to 60 V at the Core's pack inputs. Lift: 14S lithium-ion, 42.0 to 58.8 V (50.4 V nominal). Range: 6S lithium-ion, 18.0 to 25.2 V (21.6 V nominal) | KWC-DDR-001, D3 |
| Pack size and mass | Lift: two ColdCell 14S3P lithium-ion packs, 410 x 94 x 94 mm, 4.46 kg and 680 Wh each (CCL-DWG-002). Range: two 6S3P lithium-ion packs of 5.0 Ah cells, 138 x 75 x 82 mm, 1.40 kg and 324 Wh each (Range's figure; ColdCell has not yet drawn this pack) | Decision 8A; CCL-CAL-001 K; KWR-CAL-001 |
| Core mass | 0.99 kg: avionics, radios, GNSS, rail and locking pins; packs, payload shoe and the frame's harness excluded | Core R9; KWC-DDR-003 |

### Pictures changed

KWL-DWG-001 general arrangement Rev P4 and KWL-DWG-002 folded Rev P3; making sketches KWL-DWG-101 (top plate), 102 (bottom plate), 103 (deck), 111 (guide), 112 (payload shoe) and 113 (saddle) to Rev P2, the others redrawn unchanged; build plan overview, all eleven joints (joint-07 now the payload shoe on the Core rail, joint-11 the Core under the hub) and all sixteen steps (step 2 the hub spacers, step 6 the Core hung under the hub, step 12 the mast and antenna leads); concept media (`media/hero.png`, `cutaway.png`, `exploded.png`, `flow.png`, `concept-blueprint.png` and `.pdf` Rev P3, `model.glb`). Looked at: the general arrangement and joint-11. `cad/src/product_model.py` takes the new parts from `model.py`; render scenes exported to `/home/claude/renders/kitewright-lift` (hero, exploded, detail). The photoreal renders, captions and cards in `media/` predate this change and need a re-run on Amish's Mac.

### Open decision 4 closed: R4 restated (consequence of 8A)

Amish Chadha, 2026-10-04: "For round 3, I agree with all your proposed recommendations". Because decision 8A rates the payload at what fits inside R1's 25 kg, R4's sea-level case no longer names 5 kg. **R4 restated** (`docs/03-requirements.md` v0.5, Amish quoted): "at least 20 min with the rated payload (R2) at sea level and 10 min with 2 kg at 5,000 m and -20 °C". Result unchanged: 20.4 min at sea level with the rated 3.2 kg and 14.5 min at 5,000 m with 2 kg, **met on paper**. Records only: no change to the model, calculations, BOM or pictures. Recorded in `docs/decisions/0005-r4-rated-payload.md` (KWL-DDR-005) and the register (`docs/06-design-decisions.md` v0.4, open decision 4 moved to Decisions made).

**Open decisions.** None. Nothing in carrying out 8A, 9A, 10A or open decision 4 needs Amish.

### Safety

- Two packs hold 1.36 kWh of lithium-ion cells: ColdCell's charge blocking below 5 °C, heater cut-outs, cell fuses and fire-resistant charging box apply in full, and the 50 °C warning lands the aircraft; on hot days flights are short.
- The deck now sits above the upper rotors and outside their discs in plan; the deck standoffs and strap buckles are checked tight before every flight.
- The tether module's margin under 25 kg is 0.07 kg: weigh it at TRL 4 before any tethered flight with it.

### Cross-repo actions

- **AvalancheScout:** the reconciled Lift puts its power harness at the Core's power board, about 12 mm above the payload shoe, and its eight motors 0.62 m out; AvalancheScout's noise check against this Lift is in its own review note. Twisting and choking Lift's pack and frame leads (its earlier option C) is now worth planning into Lift's harness at TRL 4.
- Nothing else outstanding: Core, Range, ColdCell and LakeWatch carry the same interface table.

### Recommended next step

Nothing awaits Amish. The design is ready for TRL 4 when the phase allows, as before (AltiRig thrust runs, hinge proof loads, first power-up and tethered hovers).

## 2026-10-03: Amish's requirement decisions carried out

Amish Chadha, 2026-10-03: "i agree with all the 46 recommendations you provided. please proceed." For Lift that decides item 34 (open decision 1) and item 35 (open decision 2) as recommended, option A on both; Kitewright Core's decision 33B also moves the frame power leads out of the Core and into Lift. Recorded in `docs/decisions/0003-requirement-decisions.md` (KWL-DDR-003) and the register (`docs/06-design-decisions.md`, KWL-DEC-001 v0.2). Kitewright Core, Kitewright Range and ColdCell were being updated in parallel by other sessions and were not edited.

**Changes made, each with its new result.**

- **34A, lighter fittings** (`cad/src/model.py`): hinge blocks with side pockets in the bolting end, an 18 x 46 mm window through both cheeks, and the cheeks cut away below the pivot outboard and under the stop bridge to a 15 mm top rail (0.29 to 0.19 kg each); root fittings with 12.5 mm side pockets leaving a 5 mm web and 5 mm bosses round both holes, and a 22 x 28 mm window (0.29 to 0.24 kg each); motor clamps shortened from 50 to 40 mm (0.24 to 0.19 kg each), so the arm tubes are cut to 405 mm. Saving 0.78 kg against the 1.04 kg estimated when the decision was posed: the root fittings' thin collar and the full-width bosses at their two holes leave less to remove. Highest new stress 35 MPa in the top rail under the bridge (a third of yield is 80 MPa); the bridge itself, 41 MPa, is unchanged. All constructability checks pass in the three states (flying with the float release, flying with the tether module, folded): no overlaps, nothing out of contact.
- **35A, lithium-ion ColdCell packs** (BOM line 23): 14S3P of 21700 high-power cells (4.5 Ah, 45 A), 50.4 V nominal, about 680 Wh and 3.56 kg each, in the same 126 x 232 x 85 mm envelope; ColdCell's charge blocking below 5 °C, heater cut-outs, cell-level fuse and fire-resistant charging box apply in full. USD 628 each (USD 208 more). **R4 met on paper: 20.1 min at sea level with 5 kg (target 20) and 16.1 min at 5,000 m and -20 °C with 2 kg (target 10).** About 11 A per cell in hover against 45 A.
- **Frame-to-Core power leads** (Core decision 33B; BOM line 24, build plan section 3.17a): 8 AWG wire and four AS150 halves, about 0.12 kg and USD 60; the Core is taken at 0.99 kg.

**Results against the requirements (KWL-CAL-001 v0.2).**

| Requirement | Before | Now | Status |
| --- | --- | --- | --- |
| R1, take-off mass with 5 kg (25 kg or less) | 25.5 kg | 25.2 kg; 20.2 kg ready to fly | Not met, by about 0.2 kg (decision 3 below) |
| R2, 5 kg at sea level | 4.5 kg inside R1 | 4.77 kg inside R1; thrust to weight 2.85 | At risk (decision 3 below) |
| R3, 2 kg at 5,000 m | Thrust to weight 1.94 | 1.97 | Met on paper |
| R4, hover time (20 and 10 min) | 8.9 and 7.1 min | 20.1 and 16.1 min | Met on paper |
| R5, motor out | 2.20 and 1.51 | 2.22 and 1.53 | Met on paper |
| R7, tethered endurance | Converter margin 1.35 | 1.37 | Met on paper |
| R10, temperature | 53 Wh pre-heat | 58 Wh pre-heat | Met on paper |
| R11, cost | USD 5,739 | Value-engineering target: USD 5,000. Estimated cost of the constructable design: USD 6,335 (USD 1,335 over the target) | Reported against the target |

R6, R8 and R9 are unchanged and met on paper. `budget_usd` is unchanged.

**Pictures changed.** KWL-DWG-001 general arrangement Rev P3 and KWL-DWG-002 folded Rev P2; making sketches KWL-DWG-104 (hinge block), 105 (root fitting), 106 (arm tube) and 107 (motor mount) Rev P2; the build plan overview, joints and steps redrawn from the model (step 13 now plugs the packs into the frame leads); concept media (`media/hero.png`, `cutaway.png`, `exploded.png`, `flow.png`, `concept-blueprint.png` and `.pdf` Rev P2, `model.glb`). `docs/05-build-plan.md` v0.2 (sections 2, 3.2, 3.5, 3.9, 3.10, 3.11, 3.17, new 3.17a, step 13, safety stop 2), `docs/04-calcs/01-sizing.md` v0.2, `docs/03-requirements.md` v0.3, `docs/02-concept.md` and `README.md` figures. Appearance model (`cad/src/product_model.py`) takes the lightened parts from `model.py`; scenes re-exported to `/home/claude/renders/kitewright-lift` (hero, exploded, detail). The photoreal renders on Amish's Mac predate this change and should be re-rendered.

**Decision for Amish.**

*Decision 3: R1 and R2, take-off mass with a 5 kg payload, after decisions 34A and 35A.* State: the aircraft weighs 25.2 kg with a 5 kg payload, about 0.23 kg over R1; inside R1 it carries 4.77 kg. Cause: the lightened fittings saved 0.78 kg rather than the estimated 1.04 kg, the lithium-ion packs add 0.44 kg and the frame-to-Core leads 0.12 kg. R1 sits at the 25 kg line that matters for permissions (the US Part 107 class is under 55 lb, 24.9 kg), so restating R1 upward has a cost beyond the number.

| Option | Effect on R1 and R2 | Cost | Mass |
| --- | --- | --- | --- |
| A: rate the sea-level payload at 4.7 kg (restate R2 as "4.7 kg on the core mount at sea level"); the TRL 4 weigh-in sets the final rating | R1 met at 24.9 kg; R2 met as restated; R4 20.3 min. The float release (1.6 kg) and tether module (3.3 kg) both fit | None | None |
| B: lightening windows in the battery deck (two 80 x 160 mm under the packs) and the top hub plate (four 60 x 50 mm), and rate the payload at 4.9 kg | R1 met at 24.95 kg with 4.9 kg; deck and plate stiffness to be checked | About USD 15 more routing (estimate) | About 0.18 kg less |
| C: restate R1 to 25.5 kg and keep the 5 kg payload | Both met as restated | None | None, but above the 24.9 kg (55 lb) line, so more permission paperwork at test sites |

**Recommendation: A.** It costs nothing, every payload designed so far is well under 4.7 kg, it keeps Lift inside the 25 kg class, and the real mass from the TRL 4 weigh-in (bought masses are class estimates) decides whether the full 5 kg can be restored. Listed in the register as open decision 3, "Proposed, awaiting Amish".

**Cross-repo actions** (not edited here):

- **ColdCell:** add and confirm the lithium-ion variant for Lift (decision 35A): 14S3P of 21700 high-power cells, 4.5 Ah and 45 A, about 680 Wh and 3.56 kg, in the 126 x 232 x 85 mm envelope, 85 % of rated energy at -20 °C with the heater running; charge blocking below 5 °C, heater cut-outs, cell-level fuse and fire-resistant charging box. Lift's R4 margin at sea level is 0.1 min, so a lower energy figure from ColdCell would put R4 at risk again.
- **Kitewright Core:** Lift now supplies the pack and frame leads (8 AWG, AS150) soldered to the Core's pads (decision 33B), and takes the Core at about 0.99 kg.

**Safety.** Lithium-ion packs carry more fire energy than the LiFePO4 packs first planned: the build plan's section 3.17 and safety stop 2 now require ColdCell's charge blocking below 5 °C, heater cut-outs, cell fuses and charging only in the fire-resistant box, and a polarity and insulation check of the new frame-to-Core leads before the first pack is plugged in. The lightened hinges keep every stress under a third of yield and are still proof-loaded to 117 N m before first flight.

**Recommended next step.** Amish decides decision 3; ColdCell confirms its lithium-ion variant. The design is then ready for TRL 4 when the phase allows (unchanged from the TRL 3 recommendation below).

## Session 2026-10-03: TRL 3 (kit 1.7.0, /to-trl3 under Amish's pre-approvals)

Amish, 2026-10-03: "start with the first 14 repos from the list of 29 projects. I pre-approve the batch runs along with any recommendations you come up with. I also accept any cost overruns or variations from the assumed scope cost." and, for this second batch, "Proceed with the remaining 15 scaffolds". Every design recommendation in this session is therefore recorded as decided, dated 2026-10-03, in `docs/06-design-decisions.md`. Requirements not met or at risk are not decided; they are posed below under "Decisions for Amish" (Amish, 2026-10-03: "A simple statement doesn't add value - ensure you are identifying a state and posing it as a clear recommendation for me to decide on."). Kit 1.7.0 was installed from the kit source; `.kit/PHASE.yaml` kept as installed. Kitewright Core and Kitewright Range were worked on in parallel by other sessions; their repositories were not touched, and the interface sizes Lift assumes are listed under "Cross-repo actions".

### TRL 2

**What was done.**

- `docs/01-problem.md` (KWL-PRB-001 v0.2): first co-design candidate with a checklist, answers to the TRL 1 open questions, safety section; the budget restated as a value-engineering target.
- `docs/03-requirements.md` (KWL-REQ-001 v0.2): status of every requirement; targets unchanged.
- `docs/02-concept.md` (KWL-PRC-001 v0.2): how it works, components, key design choices, first-order numbers, safety.
- `docs/decisions/0001-trl2-review-decisions.md` (KWL-DDR-001): fourteen TRL 2 review items decided.

**Results.** A coaxial X8 with 30 inch propellers on 1,240 mm motor spacing lifts the R2 and R3 payloads with ample thrust and keeps flying after the loss of any one motor. The open questions were the arm fold (which way, and what holds the arm in flight), the pack chemistry's effect on hover time, and the tether voltage.

**Requirements not met.** None decided at TRL 2; R4 (hover time) was already doubtful with the ColdCell LiFePO4 chemistry.

**Decisions made under the pre-approvals.** KWL-DDR-001, items 1 to 14: coaxial X8; arms fold down against a stop bridge, lock pin against droop only; 30 inch propellers, 100 KV class motors, controllers on the arms; two ColdCell LiFePO4 16S2P packs as the baseline; fixed 400 V tether with a monitored isolated supply and a breakaway; no winch until screened; fail-closed float release with the line never tied to the aircraft and drops from 10 m or higher; the Core payload mount and one payload plate; fixed skid gear; 15 m keep-out; the Himalayan Rescue Association as first co-design candidate and Khumbu, Nepal as first high-altitude region (neither agreed); AltiRig and CalRig as first proof rigs; budget kept.

**Safety concerns.** Propeller strike; an arm folding in flight; pack fire after a crash or cold charge; the 400 V tether; downwash on people in water or on snow.

### TRL 3

**What was done.**

- `docs/04-calcs/01-sizing.md`, `docs/04-calcs/sizing.py` and `docs/04-calcs/results.csv` (KWL-CAL-001 v0.1): mass, hover power and time, thrust margin and motor out, wind, structure, tether, float drop, transport, temperature, cost.
- `cad/src/model.py`: parametric build123d model with constructability checks in three states (flying with the float release, flying with the tether module, folded): no overlaps, nothing floating. STEP in `cad/step` (assembly, folded, tether module and eleven made parts) and STL in `cad/stl`.
- `cad/src/sheets.py`: KWL-DWG-001 general arrangement (Rev P2) and KWL-DWG-002 folded arrangement (Rev P1).
- `bom/bom.csv`: 38 lines, all priced, with suppliers by type; lines 1 to 25 are the aircraft, 26 to 38 the payloads and tether ground set.
- `cad/src/concept_media.py`: `media/hero.png`, `cutaway.png`, `exploded.png`, `flow.png`, `concept-blueprint.png` and `.pdf` (KWL-DWG-010), `model.glb` (about 3 MB, coarse tessellation) and `viewer.html`.
- `docs/decisions/0002-design-for-construction.md` (KWL-DDR-002); `design_state: constructable`.
- `cad/src/build_plan_media.py`: overview, fourteen making sketches (KWL-DWG-101 to 114), eleven joint close-ups and sixteen step pictures; `docs/05-build-plan.md` (KWL-BLD-001) and `docs/06-design-decisions.md` (KWL-DEC-001).
- `cad/src/product_model.py` (`product_parts()`, `TITLE`, `RENDER_VIEWS` hero, exploded, detail); scenes exported to `/home/claude/renders/kitewright-lift` (three .npz and .json, `kitewright-lift__jobs.json`). Photoreal renders, captions and cards are made on Amish's Mac; the README already leads with `media/render-hero.png`.
- `README.md`, `project.yaml` (trl 3, trl_target 3).

**Results (KWL-CAL-001).** Empty 13.8 kg (made parts 6.15 kg from the model); two packs 6.68 kg and 614 Wh; ready to fly 20.5 kg; 25.5 kg with 5 kg. Hover power 3.30 kW at sea level with 5 kg and 3.51 kW at 5,000 m and -20 °C with 2 kg; hover time 8.9 and 7.1 min. Thrust to weight 2.83 at sea level and 1.94 at 5,000 m; with one motor out 2.20 and 1.51. Wind: 18 N and 4.2 degrees at 10 m/s. Structure at full thrust: 2.6 kN on the stop bridge (41 MPa), 2.8 kN on the 8 mm pivot (27.5 MPa), arm tube 28 MPa and 0.76 mm deflection; hinge proof load 117 N m. Tether: 3.32 kW from the ground, 23 V drop, 193 W loss, converter at 74 % of rating. Float drop: expected miss 2.2 m from 10 m in 10 m/s wind. Folded 0.84 x 0.48 x 0.45 m; set-up about 9 min. Value-engineering target: USD 5,000. Estimated cost of the constructable design: USD 5,739 (USD 739 over the target); payloads and ground set USD 3,716.

**Requirements not met or at risk.**

- **R1, not met, and R2, at risk:** 25.5 kg with a 5 kg payload; the payload that fits inside R1 is 4.5 kg.
- **R4, not met:** 8.9 min at sea level with 5 kg and 7.1 min at 5,000 m and -20 °C with 2 kg.
- R3, R5, R7, R8, R9 and R10 are met on paper; R6 is met for thrust and the position hold is shown in flight; R11 is reported against the value-engineering target (USD 739 over), not as a decision.

**Decisions for Amish.**

*Decision 1: R1 and R2, take-off mass with a 5 kg payload.* State: the aircraft weighs 25.5 kg with a 5 kg payload, 0.5 kg over the R1 limit; inside R1 it carries 4.5 kg. Cause: the machined aluminium fittings (hinge blocks, root fittings, motor clamps: 3.26 kg) are sized as simple pocketed blocks for a first prototype, and the LiFePO4 packs weigh 6.68 kg.

| Option | Effect on R1 and R2 | Cost | Mass |
| --- | --- | --- | --- |
| A: pocket the hinge blocks, root fittings and motor clamps deeper (side pockets leaving 4 to 5 mm walls and webs round the holes; stresses stay under a third of yield) | 24.4 kg with 5 kg: both met; hover time +0.6 min | About USD 120 more machining | 1.04 kg less |
| B: rate the sea-level payload at 4.5 kg | R1 met; R2 not met by 0.5 kg | None | None |

**Recommendation: A.** It meets both requirements for a small machining cost, and the saving also helps R4 under either option of decision 2.

*Decision 2: R4, hover time.* State: 8.9 min at sea level with 5 kg and 7.1 min at 5,000 m and -20 °C with 2 kg, about 45 % and 70 % of the R4 figures. Cause: the ColdCell LiFePO4 packs hold 92 Wh/kg once heater, BMS and shell are added, and a 25 kg aircraft needs 3.3 kW to hover; more LiFePO4 cells push the take-off mass past R1.

| Option | Effect on R4 | Cost | Mass |
| --- | --- | --- | --- |
| A: a lithium-ion ColdCell variant for Lift, 14S3P of 21700 high-power cells (2 x 680 Wh, same 51 V class bus), with decision 1 A | 20.5 min at sea level with 5 kg and 16.5 min at 5,000 m with 2 kg: met; take-off mass 24.9 kg | About USD 416 more | 0.44 kg more than the LiFePO4 packs (net 0.6 kg less with 1 A) |
| B: LiFePO4 with a third cell in parallel (16S3P) | 13.8 min at sea level but only 1.7 kg of payload inside R1; 9.0 min at 5,000 m: not met, and R2 worse | About USD 130 more | 2.9 kg more |
| C: keep the LiFePO4 16S2P packs for the first prototype and use the tether for long hovers | 8.9 and 7.1 min (9.5 and 7.7 with 1 A): not met | None | None |

**Recommendation: A.** It is the only option that meets R4 at both sea level and altitude while keeping R1, and it leaves motors, controllers and the Core bus unchanged. It needs ColdCell to accept a lithium-ion variant (its problem statement now limits it to LiFePO4 or sodium-ion), so it is listed under Cross-repo actions; lithium-ion cells carry more fire energy, and ColdCell's charge lockout, heater cut-off and pack enclosure rules apply in full.

**Decisions made under the pre-approvals.** KWL-DDR-002, the fourteen design-for-construction changes (listed below); the appearance model additions (below). All in `docs/06-design-decisions.md`. Open decisions: the two above, "Proposed, awaiting Amish".

**Build plan findings (design changes made for construction, KWL-DDR-002).**

1. Arm hinge: clevis block with an 8 mm pivot near the bottom, a ball-lock pin, and a stop bridge 30 mm outboard of the pivot that takes the lift.
2. One-piece root fitting: tongue in the clevis and a collar round the tube, bonded and cross-bolted.
3. Pivot moved to 180 mm and plate corners cut at 162 mm, so the folded root fitting clears the bottom plate (it overlapped by 960 mm3).
4. Hub: two 3 mm carbon plates 60 mm apart on the hinge blocks and four spacers; the Core inside on dampers.
5. Battery deck on standoffs with guides and cam straps; packs clear of the hinge pins and rotors.
6. Split clamp motor mount thick enough above the tube for the motor screws.
7. Controllers on the arms; only two power leads per arm cross the hinge.
8. Hub 500 mm up and skids 450 mm apart, so the folded motors clear the ground (32 mm) and skids (17 mm).
9. Core payload rails, pin and socket under the hub; one standard payload plate.
10. Float release from a plate, printed saddles, a bought fail-closed release and a sewn sling.
11. Tether module on the same plate, with a breakaway connector.
12. GNSS mast on the deck centre.
13. Spacers and standoffs on the axes at 130 mm, clear of the pack straps (they overlapped).
14. Lightening pocket and window in the hinge blocks and root fittings (from 0.62 to 0.29 kg each).

**Appearance model.** `product_model.py` uses the `model.py` solids, flying-ready with the float release. Additions not in `model.py`: a 1.75 m mannequin (`mannequin()`, standing) beside the aircraft, to the left of it and slightly behind it as seen by the hero camera, never between the camera and the aircraft; and, for the detail view, one arm hinge in its own frame with short pieces of the hub plates and arm tube. Decided under the pre-approvals.

**Cross-repo actions** (shared-interface assumptions for the sibling sessions to confirm or correct; no sibling repository was edited):

- **Kitewright Core:** the stack fits 150 x 100 x 40 mm on four 10 mm rubber dampers at 130 x 80 mm centres, and weighs 1.0 kg with its payload mount (Core R9).
- **Kitewright Core:** payload mount as two rails 260 x 20 x 22 mm, inner faces 112 mm apart, with 8 mm x 8 mm slots; a 6 mm ball-lock payload pin through both rails 105 mm ahead of the centre and 8 mm below the mounting face; a DS-014 socket block 20 x 60 x 16 mm at the back, its face 132 mm behind the centre; M4 fixings into the frame; a standard payload plate 240 x 124 x 6 mm with a lock lug and plug pad. Range should use the same plate if its pod allows.
- **Kitewright Core:** the power bus takes two ColdCell packs at about 51 V and a tether input (51 V from an onboard isolated converter, up to 4 kW, ORed with the packs) without adaptive tether voltage.
- **ColdCell:** a 16S2P LiFePO4 pack of 26650 power cells (3.0 Ah, 30 A), 126 x 232 x 85 mm, about 3.3 kg and 307 Wh, plugging into the Core bus; the cells must be power-rated (16 A per cell in hover).
- **ColdCell:** if Amish chooses decision 2 A, a lithium-ion variant (14S3P 21700 high-power cells, about 680 Wh and 3.6 kg) in the same envelope; this widens ColdCell's chemistry constraint.
- **AltiRig:** measure a 30 x 10 propeller on a 100 KV class motor at sea level and 5,000 m density, upper and lower rotor of a coaxial pair 170 mm apart.
- **Kitewright Range:** if Range uses the same motors or packs, share the AltiRig and ColdCell results; Lift's arm hinge is not shared.

**Safety concerns.**

- An arm folding in flight would be fatal to the aircraft; the stop bridge carries the lift so the pin never does, and each hinge is proof-loaded to 1.5 times its full-thrust moment before first flight (safety stop).
- Eight 30 inch propellers: 15 m keep-out when armed; first power with propellers off.
- The 400 V tether is a dangerous voltage: isolated, monitored supply, residual-current protection, emergency stop, breakaway, no handling while live, 50 m highest hover.
- Pack fire after a crash or a cold charge; ColdCell's rules apply, and more so with a lithium-ion variant.
- Downwash (about 7.5 m/s at 10 m, estimated) can push a person in water under or knock someone over on snow; drops from 10 m or higher, and the figure is to be measured.
- The motor-out case is on paper only; yaw control after a motor loss is shown in a cut test over cleared ground.

**Recommended next step.** After Amish decides the two items above (and ColdCell confirms its pack envelope), the design is ready for TRL 4 when the phase allows: AltiRig thrust runs, hinge proof loads on CalRig, first power-up and tethered hovers, then the motor-cut and drop trials with the first co-design candidate. Suggestion not added to the repo: a snow and soft-ground foot that clips onto the skids.

## Session 2026-09-30: scaffolded

### What was done

- Repository created from kit 1.6.0 at TRL 1, target TRL 2.
- `docs/01-problem.md` (KWL-PRB-001 v0.1): problem with cited evidence, users, environment, constraints, prior work, open questions.
- `docs/02-concept.md` (KWL-PRC-001 v0.1): how it works, components, patent design-arounds, shared blocks, safety.
- `docs/03-requirements.md` (KWL-REQ-001 v0.1): 11 proposed requirements.
- `README.md` with concept rationale, burning platform, where it could be used, and what sparked the idea.

### Next

- Run `/populate` to bring the repo to a strong TRL 2 with concept media.

## 2026-10-03: photoreal renders

Rendered with Blender Cycles on Amish's Mac from `cad/src/product_model.py`; captioned with `.kit/photo_caption.py`; `media/card.png` and `media/social-preview.png` made with `.kit/cards.py`. Views: hero, exploded, detail. image_qc passes and `render.py --check` has no FAIL.

## 2026-10-04: photoreal renders redone after the round-2 and round-3 decisions

Views: hero, exploded, detail; cards regenerated; image_qc passes and `render.py --check` has no FAIL.

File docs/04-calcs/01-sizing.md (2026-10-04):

---
doc_id: KWL-CAL-001
title: Kitewright Lift sizing calculations
project: Kitewright Lift
doc_type: Calculation
version: "0.3"
status: Draft
date: '2026-10-04'
author: Amish Chadha
license: CERN-OHL-S-2.0
revisions:
- version: "0.1"
  date: '2026-10-03'
  author: Amish Chadha
  change: First sizing of the constructable design (KWL-DDR-002) against every requirement
- version: "0.2"
  date: '2026-10-03'
  author: Amish Chadha
  change: Amish's decisions 34A and 35A (KWL-DDR-003); lightened fittings from the model, lithium-ion ColdCell packs, frame-to-Core power leads and a 0.99 kg Core (Core decision 33B); new results for R1, R2, R3, R4, R5, R7, R10 and R11
- version: "0.3"
  date: '2026-10-04'
  author: Amish Chadha
  change: Amish's round-3 decisions 8A, 9A and 10A (KWL-DDR-004); ColdCell's packs as drawn (4.46 kg, 410 x 94 x 94 mm) on a re-sized, raised deck; the Kitewright Core to the family envelope with payload shoes; rated payload and R1, R2 as restated; deck check added; every section re-run
---

# Kitewright Lift sizing calculations

This version carries out Amish's round-3 decisions of 2026-10-04 (KWL-DDR-004): "For round 3, I agree with all your proposed recommendations". ColdCell's lithium-ion pack as drawn (410 x 94 x 94 mm, 4.46 kg, 680 Wh) is Lift's pack (8A); the aircraft keeps the 25 kg take-off limit (the US 55 lb class) and is rated for the payload that fits; ColdCell's 50 °C warning sets a warm-weather limit (9A); and the Kitewright Core hangs under the hub to the family envelope with AS150 plugs everywhere (10A). With two of these packs on a re-sized, raised 2 mm deck the aircraft weighs 21.8 kg ready to fly, so the rated payload is **3.2 kg** at 25.0 kg take-off mass; the float release (1.46 kg) and the tether module (3.13 kg) both fit. Every requirement is met on paper as restated; R11 is reported against its value-engineering target.

Every number comes from `docs/04-calcs/sizing.py`, which reads made-part masses and the folded envelope from the build123d model (`cad/src/model.py`) and prices from `bom/bom.csv`, and writes `docs/04-calcs/results.csv`. All results are first-order estimates; nothing has been measured.

## Assumptions

*Table 1. Assumptions.*

| Quantity | Value | Basis |
| --- | --- | --- |
| Air at sea level; at 5,000 m and -20 °C; at sea level and +45 °C | 1.225; 0.743; 1.109 kg/m3 | ISA pressure (101.3 and 54.0 kPa), ideal gas |
| Rotors | 8 x 30 inch (0.762 m), coaxial pairs on four arms | KWL-DDR-001, item 1 |
| Coaxial induced power factor | 1.28 against two isolated rotors | Leishman, momentum theory with the lower rotor in the upper's slipstream |
| Figure of merit; motor and controller efficiency | 0.65; 0.80 | Typical for 30 inch carbon propellers and 100 KV motors in hover |
| Full-throttle thrust per motor at sea level | 10 kg; lower rotor 80 % of that in a pair | Maker's class figure; to be measured on AltiRig |
| Avionics and payload power | 35 W and 15 W | Core stack; release servo or converter control |
| Pack | ColdCell 14S3P lithium-ion pack as drawn: 21700 high-power cells, 4.5 Ah, 3.6 V, 45 A; 680 Wh, 410 x 94 x 94 mm, 4.46 kg with heater, insulation, BMS, shell and AS150 lead (v0.2 assumed 3.56 kg in 126 x 232 x 85 mm; the LiFePO4 16S2P pack of v0.1 kept for comparison: 26650 cells, 3.0 Ah, 85 g, 30 A) | Decision 8A; CCL-DWG-002 and CCL-CAL-001 K |
| Take-off limit and rated payload | 25 kg (the US 55 lb class); the rated payload is the largest 0.1 kg step that fits | R1 and R2 as restated (KWL-REQ-001 v0.4) |
| Energy used per flight | 80 % of nominal; 85 % of that at -20 °C | 20 % kept to land; ColdCell R1, assumed to hold for the lithium-ion variant with its heater running |
| Drag area, side on | 0.30 m2 | Hub, packs, gear and payload (estimate) |
| Bought masses | Motors 450 g, controllers 110 g, propellers 110 g, Core 0.99 kg with its rail and pins, wiring 0.65 kg plus 0.12 kg of frame-to-Core leads and 0.03 kg of antenna extension leads, fasteners and epoxy 0.25 kg | Class figures; Core R9, Core decision 33B; Kitewright interface table |
| Tether | 400 V DC fixed, 60 m, 2 x 0.75 mm2 copper, 25 g/m, 50 m highest hover; converter 95 %, 4 kW | KWL-DDR-001, item 5 |
| Float | 0.85 kg, 0.12 x 0.42 m, drag coefficient 0.9 | Foam float with line bag |

## A. Mass

Made parts from the model weigh 5.08 kg: hinge blocks 0.77, root fittings 0.94, motor clamps 0.76, arm tubes 0.60, hub plates 0.58 (the bottom plate is 0.11 kg lighter for the Core's 200 x 112 mm opening), deck 0.28, gear 0.88, pivots 0.13, guides 0.08, spacers 0.06. Bought parts weigh 7.78 kg, so the aircraft weighs 12.9 kg empty. Each ColdCell pack holds 680 Wh in 4.46 kg (153 Wh/kg); two weigh 8.92 kg, 1.80 kg more than the 3.56 kg packs v0.2 assumed.

*Table 2. Where the mass moved (decisions 8A and 10A), against v0.2.*

| Change | Mass |
| --- | --- |
| Two ColdCell packs as drawn, 4.46 kg each (3.56 kg assumed) | +1.80 kg |
| Deck re-sized to 430 x 280 mm, made 2 mm (was 330 x 290 x 3 mm), with four 120 x 60 mm windows | -0.16 kg |
| Pack guides of 15 x 15 x 1.5 mm angle, 340 mm (were 20 x 20 x 2, 250 mm) | -0.02 kg |
| Bottom hub plate: Core opening in place of the damper, rail and socket holes | -0.11 kg |
| Deck standoffs 60 mm (were 25), antenna extension leads | +0.04 kg |
| Ready to fly | 20.23 to 21.78 kg (+1.55 kg) |

*Table 3. Take-off mass and payloads.*

| Case | Mass |
| --- | --- |
| Ready to fly, no payload | 21.78 kg |
| Payload allowance inside 25 kg | 3.22 kg |
| Rated payload (R2 as restated) | 3.2 kg, 24.98 kg take-off |
| Float release payload, on its own payload shoe | 1.46 kg (23.24 kg take-off) |
| Tether module, with 1.25 kg of tether hanging at 50 m | 3.13 kg (24.91 kg take-off) |
| With 2 kg (R3 and R4 at altitude) | 23.78 kg |
| With 5 kg (the v0.2 rating, for comparison) | 26.78 kg, over R1 |

**R1 and R2 are met on paper as restated.** The payload modules weigh less than in v0.2 (1.58 and 3.25 kg) because each now hangs from a 184 x 128 x 5 mm payload shoe to the Core's KWC-DWG-106 in place of the 240 x 124 x 6 mm plate with its lug. The tether module's margin is 0.07 kg, so the TRL 4 weigh-in decides it.

## B. Hover power

Hover power is the momentum-theory power for the total thrust over the eight rotor discs, raised by the coaxial factor and divided by the figure of merit and drive efficiency:

P = 1.28 x T^1.5 / sqrt(2 ρ A) / (0.65 x 0.80) + avionics and payload

with T the weight in newtons and A the area of all eight discs (3.65 m2).

*Table 4. Hover power.*

| Case | Power |
| --- | --- |
| Sea level, rated payload (25.0 kg) | 3.21 kW |
| Sea level, no payload | 2.61 kW |
| 5,000 m and -20 °C, 2 kg | 3.82 kW |
| Sea level and +45 °C, rated payload | 3.37 kW |
| Tethered at sea level | 3.20 kW |

Disc loading is 134 N/m2 on the four projected discs and the induced velocity 7.4 m/s.

## C. Hover time (R4)

*Table 5. Hover time with two ColdCell packs (1,361 Wh).*

| Case | Hover time |
| --- | --- |
| Sea level, rated payload (25.0 kg) | 20.4 min |
| Sea level, float release | 22.6 min |
| Sea level, no payload | 25.1 min |
| 5,000 m and -20 °C, 2 kg | 14.5 min |
| Sea level and +45 °C, rated payload | 19.4 min of energy; ColdCell's warning limits it (section J) |

**R4 is met on paper** with the rated payload: 20.4 min against 20 min at sea level, and 14.5 min against 10 min at 5,000 m with 2 kg. A 5 kg payload no longer fits inside R1, so R4's sea-level case is read at the rated payload. The pack draws 64 A in hover, 10.6 A per cell (15.9 A in a climb), well inside the 45 A cell rating.

## D. Thrust margin and motor out (R3, R5)

A coaxial pair gives 18 kg at full throttle at sea level (10 kg plus 80 % of 10 kg), and 61 % of that at 5,000 m and -20 °C.

- Thrust to weight: 2.88 at sea level with the rated payload; **1.84 at 5,000 m with 2 kg (R3 met on paper)**.
- One motor out: the failed arm keeps its partner. Thrust to weight with one motor out is **2.24 at sea level and 1.43 at 5,000 m (R5 met on paper)**. Yaw control after a motor loss is shown in the motor-cut test.
- One motor at full throttle draws about 1.8 kW, 38 A: inside the 80 A controller rating.

## E. Wind (R6)

At 10 m/s the drag is 18 N, so the aircraft leans 4.3 degrees and needs 0.3 % more thrust; a 15 m/s gust needs 9.6 degrees. Holding position within 2 m depends on the autopilot tuning and is shown in flight.

## F. Arms, hinges, deck and gear

At full throttle one arm lifts 177 N, 440 mm outboard of its pivot: 78 N m about the pivot.

*Table 6. Structure at full thrust (hover in brackets), and the deck at a 3 g landing.*

| Item | Load | Stress or factor |
| --- | --- | --- |
| Stop bridge, 30 mm outboard of the pivot | 2.59 kN (0.90 kN) | Bending 41 MPa in 6061-T6 (yield 240 MPa); bearing 8.6 MPa |
| Pivot bolt, 8 mm, double shear | 2.77 kN | 27.5 MPa |
| Hinge cheeks, 7 mm, at the pivot | 2.77 kN | Bearing 24.7 MPa |
| Arm tube, 40 x 36 carbon, at the collar | 177 N at 340 mm | Bending 28 MPa; tip deflection 0.76 mm (0.27 mm) |
| Lock pin, 3 g landing, arm about 2.2 kg | 16.2 N m, 613 N | Shear 6.1 MPa |
| Hinge block cheeks at the window | 81 N m | Bending 18 MPa |
| Hinge block top rail under the bridge | 1.30 kN per cheek | Bending 35 MPa; shear 12 MPa |
| Root fitting tongue, web and window | 39 and 71 N m | Bending 6 and 8 MPa |
| Battery deck, 2 mm carbon, both packs at 3 g on the two standoffs at X = 130 mm (decision 8A) | 3.6 N m at mid-span | 19 MPa at mid-span, 27 MPa through the windows; overhang tip 0.27 mm |
| Gear strut, 3 g touchdown on one skid | 189 N | 2.2 MPa |

Every item is far inside its material's strength; the carbon deck runs at about a tenth of a 250 MPa allowable. The hinge proof load before first flight is 1.5 times the full-thrust moment, 117 N m. With the heavier packs on the raised deck the aircraft tips over on a slope of 14.5 degrees along its short gear axis (15.3 in v0.2).

## G. Tethered hover (R7)

The tether loop is 2.80 ohm. At 24.9 kg the aircraft needs 3.20 kW; 9.0 A flows, the tether drops 25 V and loses 225 W, and the ground supply gives 3.59 kW. The 4 kW converter runs at 80 % of its rating (margin 1.25, above the 1.2 the design keeps). Two hours of tethered hover take 7.2 kWh from the ground supply. **R7 is met on paper**; the converter's and motors' temperatures over two hours are measured at TRL 4.

## H. Float drop (R8)

A float dropped from 10 m falls for 1.43 s and hits the water at 14 m/s. In 10 m/s wind it drifts about 3.3 m; aiming off for the drift leaves about 30 % of it. With the 2 m position hold of R6, the expected miss is **2.2 m (R8 met on paper)**. The downwash about 10 m below the aircraft is about 7.4 m/s (estimate).

## I. Transport and clearances (R9)

The folded model measures 451 x 480 x 876 mm with the gear on (the GNSS mast is 34 mm taller on the raised deck), so it stands in a 1.2 x 0.6 x 0.5 m case on its skids. Folded, the motors are 32 mm above the ground and 17 mm clear of the skids. Set-up takes about 9 min. **R9 is met on paper.**

The deck now stands on 60 mm standoffs so that its underside is 9 mm above the upper blades, and in plan the deck's corner cuts stay 12.7 mm and the pack corners 22.7 mm outside the upper discs, so neither reaches into the rotor path. Lower discs are 99 mm from the gear struts and 54 mm from the float; tip to tip 115 mm. The Core's lid stands up through the bottom plate into the hub; its mast boss, SMA bulkheads and switch reach holes in the top plate, and the boss top is 57 mm below the deck.

## J. Temperature (R10)

Warming the 5.9 kg of cells in both packs by 30 K takes about 58 Wh from the ground supply before take-off; ColdCell blocks charging below 5 °C. The motors, controllers, carbon and aluminium parts are rated from -20 to +45 °C. ColdCell keeps its 50 °C firmware warning for this pack until a TRL 4 measurement supports relaxing it (decision 9A): a full hover flight stays under it up to about 27 °C ambient, and at +45 °C the warning comes after about 6 min of hover (CCL-CAL-001 K). **R10 is met on paper by part ratings, with full-length hover flights limited to about 27 °C ambient;** hotter days mean shorter flights.

## K. Cost (R11)

Value-engineering target: USD 5,000. Estimated cost of the constructable design: USD 6,627 (USD 1,627 over the target). Against v0.2 (USD 6,335) ColdCell's packs cost USD 268 more (USD 762 each, against USD 628 assumed), the larger 2 mm deck USD 5, longer straps USD 4 and the antenna extension leads USD 15. The payloads and ground equipment, now with ColdCell's pre-heat supply, charger and fire-resistant charging box (USD 255), add USD 3,976.

## Results against requirements

*Table 7. Results.*

| ID | Requirement | Result | Status |
| --- | --- | --- | --- |
| R1 | Maximum take-off mass, 25 kg including the rated payload | 24.98 kg with 3.2 kg; 21.78 kg ready to fly | Met on paper as restated |
| R2 | Rated payload at sea level, 3.2 kg; both designed payloads fit | Float release 1.46 kg, tether module 3.13 kg; thrust to weight 2.88 | Met on paper as restated |
| R3 | Payload at altitude | Thrust to weight 1.84 at 5,000 m and -20 °C with 2 kg | Met on paper |
| R4 | Hover time | 20.4 min at sea level with the rated payload; 14.5 min at 5,000 m with 2 kg | Met on paper at the rated payload |
| R5 | Motor-out tolerance | Thrust to weight with one motor out 2.24 and 1.43 | Met on paper |
| R6 | Wind | 18 N drag, 4.3 deg tilt at 10 m/s | Met on paper (thrust) |
| R7 | Tethered endurance | 3.2 kW hover; converter margin 1.25 | Met on paper |
| R8 | Float and line drop | Expected miss 2.2 m | Met on paper |
| R9 | Transport | 0.88 x 0.48 x 0.45 m; about 9 min set-up | Met on paper |
| R10 | Operating temperature | Part ratings; 58 Wh pre-heat; full hover flights to about 27 °C ambient | Met on paper, warm-weather limit stated |
| R11 | Prototype cost | USD 6,627 | USD 1,627 over the value-engineering target |

> **Safety:** These figures size a 25 kg class aircraft with 30 inch propellers, 1.36 kWh of lithium-ion cells and a 400 V tether. ColdCell's charge blocking below 5 °C, heater cut-outs, cell fuses, fire-resistant charging box and 50 °C warning apply in full. They are estimates; the proof loads, bench thrust runs and tethered runs listed in the build plan (KWL-BLD-001) come before any flight.

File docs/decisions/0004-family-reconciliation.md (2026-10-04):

---
doc_id: KWL-DDR-004
title: Kitewright Lift round-3 decisions, Kitewright family reconciliation
project: Kitewright Lift
doc_type: Design decision record
version: "0.1"
status: Draft
date: '2026-10-04'
author: Amish Chadha
license: CERN-OHL-S-2.0
revisions:
- version: "0.1"
  date: '2026-10-04'
  author: Amish Chadha
  change: Amish's round-3 decisions 8A, 9A and 10A carried out for Lift
---

# 0004: Kitewright family reconciliation (round 3)

- **Date:** 2026-10-04
- **Status:** accepted. Decided by Amish Chadha on 2026-10-04: "For round 3, I agree with all your proposed recommendations".

## Context

After the round-2 decisions the six Kitewright repositories disagreed. ColdCell's lithium-ion pack for Lift, built to ColdCell's rules, came out at 410 x 94 x 94 mm and 4.46 kg against the 126 x 232 x 85 mm and 3.56 kg Lift had assumed (ColdCell open decision 3); its 50 °C warning limited full hover flights to about 27 °C ambient (ColdCell open decision 4); and Lift modelled the Core as a 150 x 100 x 40 mm stack on dampers with its own rails, not to the Core's drawing. Lift's own open decision 3 (R1 and R2 at 25.2 kg with 5 kg) was still open.

## Decision

- **8A:** ColdCell's pack as drawn is Lift's pack. Lift re-sizes its battery deck, re-runs mass, hover time and thrust margins with two of these packs, keeps the 25 kg take-off limit (US 55 lb class) and rates the payload at what fits; both designed payloads must still fit. R1 and R2 restated (KWL-REQ-001 v0.4).
- **9A:** ColdCell keeps its 50 °C firmware warning for the pack until a TRL 4 measurement supports relaxing it; the warm-weather limit (about 27 °C ambient for a full hover flight) goes into the operating notes.
- **10A:** AS150 plugs everywhere; one mounting envelope for the Core shared by Lift and Range, with the Core's drawing as the reference; the Kitewright interface table in each repository's review note.

## Carried out

| Item | Was | Now |
| --- | --- | --- |
| Packs | Two 126 x 232 x 85 mm, 3.56 kg, side by side along X | Two 410 x 94 x 94 mm, 4.46 kg, side by side in Y with a 30 mm gap for the GNSS mast |
| Battery deck | 330 x 290 x 3 mm carbon on 25 mm standoffs | 430 x 280 x 2 mm carbon with four 120 x 60 mm windows on 60 mm standoffs: its underside 9 mm above the upper blades, its corner cuts 12.7 mm and the pack corners 22.7 mm outside the upper discs in plan |
| Pack guides and straps | 20 x 20 x 2 angle, 250 mm; a strap round each pack | 15 x 15 x 1.5 angle, 340 mm; four 900 mm straps round both packs |
| Kitewright Core | 150 x 100 x 40 mm stack on dampers between the hub plates; Lift's own rails, pin and socket | The Core to KWC-DWG-001: hung under the bottom plate on its 8 mm spacers (M4, 220 x 130 mm), lid up through a 200 x 112 mm opening; top plate drilled over the mast boss, SMA bulkheads and switch; GNSS on the deck mast, antennas on extension leads to the gear |
| Payload interface | 240 x 124 x 6 mm payload plate with a lock lug | 184 x 128 x 5 mm payload shoe to KWC-DWG-106; saddles 80 mm wide inside the 88 mm neck; the tether converter on four 34 mm posts below the neck, 20 mm ahead of the pin knobs |
| Connectors | AS150 and XT60 | AS150 on every pack and bus lead |

## Results (KWL-CAL-001 v0.3)

- Ready to fly 21.78 kg; rated payload 3.2 kg at 24.98 kg take-off (R1, R2 met as restated); float release 1.46 kg and tether module 3.13 kg both fit.
- Hover 20.4 min at sea level with the rated payload and 14.5 min at 5,000 m with 2 kg (R4); thrust to weight 1.84 at 5,000 m (R3); with one motor out 2.24 and 1.43 (R5); tether converter margin 1.25 (R7).
- Full hover flights to about 27 °C ambient under ColdCell's 50 °C warning (R10).
- Value-engineering target: USD 5,000. Estimated cost of the constructable design: USD 6,627 (USD 1,627 over the target).

## Consequences

- R4's target still names 5 kg at sea level, which no longer fits inside R1; posed to Amish as open decision 4.
- The tether module's margin under 25 kg is 0.07 kg: the TRL 4 weigh-in decides it.

> **Safety:** Two packs hold 1.36 kWh of lithium-ion cells. ColdCell's charge blocking below 5 °C, heater cut-outs, cell fuses, fire-resistant charging box and 50 °C warning apply in full; above about 27 °C ambient, flights are cut short when the warning comes.

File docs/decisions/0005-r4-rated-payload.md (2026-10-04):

---
doc_id: KWL-DDR-005
title: Kitewright Lift R4 restated to the rated payload (open decision 4 closed)
project: Kitewright Lift
doc_type: Design decision record
version: "0.1"
status: Draft
date: '2026-10-04'
author: Amish Chadha
license: CERN-OHL-S-2.0
revisions:
- version: "0.1"
  date: '2026-10-04'
  author: Amish Chadha
  change: Open decision 4 closed as a consequence of Amish's round-3 decision 8A
---

# 0005: R4 restated to the rated payload

- **Date:** 2026-10-04
- **Status:** accepted. Decided by Amish Chadha on 2026-10-04: "For round 3, I agree with all your proposed recommendations". Open decision 4 follows from round-3 decision 8A (the payload rated at what fits inside the 25 kg take-off limit) and is closed with its recommended option A.

## Context

R4 asked for at least 20 min of hover "with 5 kg at sea level". Under decision 8A (KWL-DDR-004) Lift keeps its 25 kg take-off limit (R1) with two ColdCell packs of 4.46 kg and rates its payload at what fits, about 3.3 kg (R2, 3.2 kg on paper). A 5 kg payload no longer fits inside R1, so the sea-level case was being read at the rated payload.

## Decision

R4 restated in KWL-REQ-001 v0.5: "At least 20 min with the rated payload (R2) at sea level and 10 min with 2 kg at 5,000 m and -20 °C (targets)". The altitude case is unchanged.

## Results (KWL-CAL-001 v0.3, unchanged)

20.4 min at sea level with the rated 3.2 kg (25.0 kg take-off) and 14.5 min at 5,000 m and -20 °C with 2 kg. **R4 met on paper.**

## Consequences

- Records only: no change to the model, calculations, BOM, drawings or pictures.
- A heavier sea-level payload would need a lighter airframe or packs in a later prototype; that is not a requirement of this one.

> **Safety:** The rated payload is the most Lift may carry; flying above it breaks R1's 25 kg limit and the class rules that rest on it.

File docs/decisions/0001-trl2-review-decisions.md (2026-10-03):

---
doc_id: KWL-DDR-001
title: Kitewright Lift TRL 2 review decisions
project: Kitewright Lift
doc_type: Design decision record
version: "0.1"
status: Draft
date: '2026-10-03'
author: Amish Chadha
license: CERN-OHL-S-2.0
revisions:
- version: "0.1"
  date: '2026-10-03'
  author: Amish Chadha
  change: TRL 2 review items decided under Amish's pre-approvals of 2026-10-03
---

# 0001: TRL 2 review decisions

- **Date:** 2026-10-03
- **Status:** accepted

## Context

The TRL 2 review (`docs/REVIEW.md`, TRL 2 section) and the open questions in KWL-PRB-001 raised the items below. On 2026-10-03 Amish wrote: "start with the first 14 repos from the list of 29 projects. I pre-approve the batch runs along with any recommendations you come up with. I also accept any cost overruns or variations from the assumed scope cost." He then wrote: "Proceed with the remaining 15 scaffolds", under the same pre-approval, which covers Kitewright Lift. Every design recommendation below is therefore decided as recommended. Choices that touch safety take the conservative option, with the evidence that would relax them stated. Partners and regions are the first candidates to approach, not agreements. Requirements that are not met or at risk on paper (R1 and R2 on mass, R4 on hover time) are not decided here; they are posed to Amish in `docs/REVIEW.md` under "Decisions for Amish".

Kitewright Core, Lift and Range are designed in parallel. Where Lift depends on a sibling (the Core stack and payload mount, the ColdCell packs), the sizes used here are interface assumptions; they are listed in `docs/REVIEW.md` under "Cross-repo actions" for the sibling designs to confirm.

## Options considered

Table 1 lists the options for each item and the one chosen.

## Decision

*Table 1. Items decided on 2026-10-03 under Amish's pre-approvals.*

| # | Item | Options | Decision | What would relax a safety choice |
| --- | --- | --- | --- | --- |
| 1 | Rotor layout | (a) flat hexacopter; (b) flat octocopter; (c) coaxial X8 (four arms, a motor above and below each tip) | (c), conservative: losing any one motor leaves its partner on the same arm, so the aircraft can still hover (thrust to weight with one motor out 2.20 at sea level and 1.51 at 5,000 m on paper). Four arms fold into a smaller bundle than six or eight. Costs about 4 % more hover power than a flat layout of the same span | Not relaxed: motor-out tolerance is a requirement (R5) |
| 2 | Arm fold | (a) arms fold up, held by a lock pin; (b) arms fold sideways; (c) arms fold down, lift pressing each arm up against a fixed stop | (c), conservative: in flight the thrust holds the arm against a stop bridge machined into the hinge block, so a lock pin left out cannot let an arm fold under power. The ball-lock pin only stops the arm drooping on the ground or in a hard landing, and carries a red flag so a missing pin is visible | Not relaxed. A proof load on CalRig of each hinge at 1.5 times the full-thrust moment is required before first flight (item 13) |
| 3 | Propeller and motor class | 28, 30 or 32 inch propellers; integrated or separate controllers | 30 inch folding carbon propellers on 1,240 mm motor spacing (115 mm tip gap); about 100 KV motors of the 10 kg static thrust class; separate 80 A controllers strapped to the arms, so motor leads never cross the hinge | Not a safety choice |
| 4 | Power bus and packs | ColdCell as designed (LiFePO4 or sodium-ion); a lithium-ion pack | Two ColdCell LiFePO4 packs, 16S2P of 26650 power cells (51.2 V, about 307 Wh each), used unchanged as the problem statement's constraint requires. The hover time this gives is posed to Amish as decision 2 in `docs/REVIEW.md`, not decided here | Charging and cold limits stay as ColdCell sets them |
| 5 | Tether power | Low-voltage tether; fixed high-voltage tether with onboard conversion; adaptive tether voltage | Fixed 400 V DC from an isolated ground supply over a 60 m tether of two 0.75 mm2 conductors; a 4 kW isolated DC-DC converter on a payload plate; a pull-release breakaway at the aircraft. Conservative: isolated supply with an insulation monitor, residual-current protection and an emergency stop at the ground; tether hover limited to 50 m. Stays clear of adaptive tether voltage (Elistair US11059580B2) | A ground-fault and touch-current test of the complete system could allow tether hover above 50 m; the isolation and monitoring stay |
| 6 | Winch | Design a winch now; reserve space only | No winch is designed or published until its own patent screen is done. The payload bay and rails take a winch module later; nothing in this design depends on one | Not a safety choice |
| 7 | Line-and-float release | Hook release; servo pin release; drop the line attached to the aircraft | A servo pin release that fails closed holds a webbing sling round a foam float; the float's line is tied to the float only and is never attached to the aircraft. Conservative: drops from at least 10 m above the person, so downwash (about 7.5 m/s estimated at 10 m) does not push them under | Downwash measured over water at lower heights could lower the 10 m drop height |
| 8 | Payload interface | Lift-specific mount; the Core payload mount | The Kitewright Core payload mount under the bottom plate: two slotted rails, a ball-lock payload pin through both rails and the payload's lug, and the DS-014 socket at the back. Interface sizes are assumptions (Cross-repo actions) | Not relaxed: the pin must be in and flagged before arming |
| 9 | Landing gear | Folding gear; fixed skids; detachable legs | Fixed skid gear, 340 mm skids 450 mm apart, hub underside 500 mm up. Fixed gear stays on for transport (the folded aircraft still fits the R9 case) and the folded motors clear the skids by 17 mm | Not a safety choice |
| 10 | Keep-out and hover heights | Set by test later; set now | Set now, conservatively: nobody within 15 m of the aircraft when armed except over a person in water for a drop; drops from 10 m or higher; no hover over people on snow slopes or rooftops | Downwash and noise measurements in the TRL 4 trials |
| 11 | First co-design candidate | A state disaster force; a volunteer mountain rescue team; a hazard research group | The Himalayan Rescue Association, Nepal, as the first candidate to approach (not agreed): it runs aid posts on the trekking routes and works with helicopter rescue at altitude | Not a safety choice |
| 12 | First high-altitude test region | Ladakh; Sikkim; Nepal's Khumbu | Sea-level trials first, then the Khumbu region of Nepal with the co-design candidate, as the first candidate (not agreed); flights only with the civil aviation authority's permission | Not a safety choice |
| 13 | Proof before flight | Fly and see; bench proof first | AltiRig as the first candidate rig for motor and propeller thrust at 5,000 m density (R3); CalRig as the first candidate rig for proof loads: each arm hinge at 1.5 times the full-thrust moment (117 N m) and the tether breakaway pull | Not relaxed |
| 14 | Prototype budget | Raise the budget; keep it | `budget_usd` kept at USD 5,000 as a value-engineering target; the estimated cost of USD 5,739 is reported against it | Not a safety choice |
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

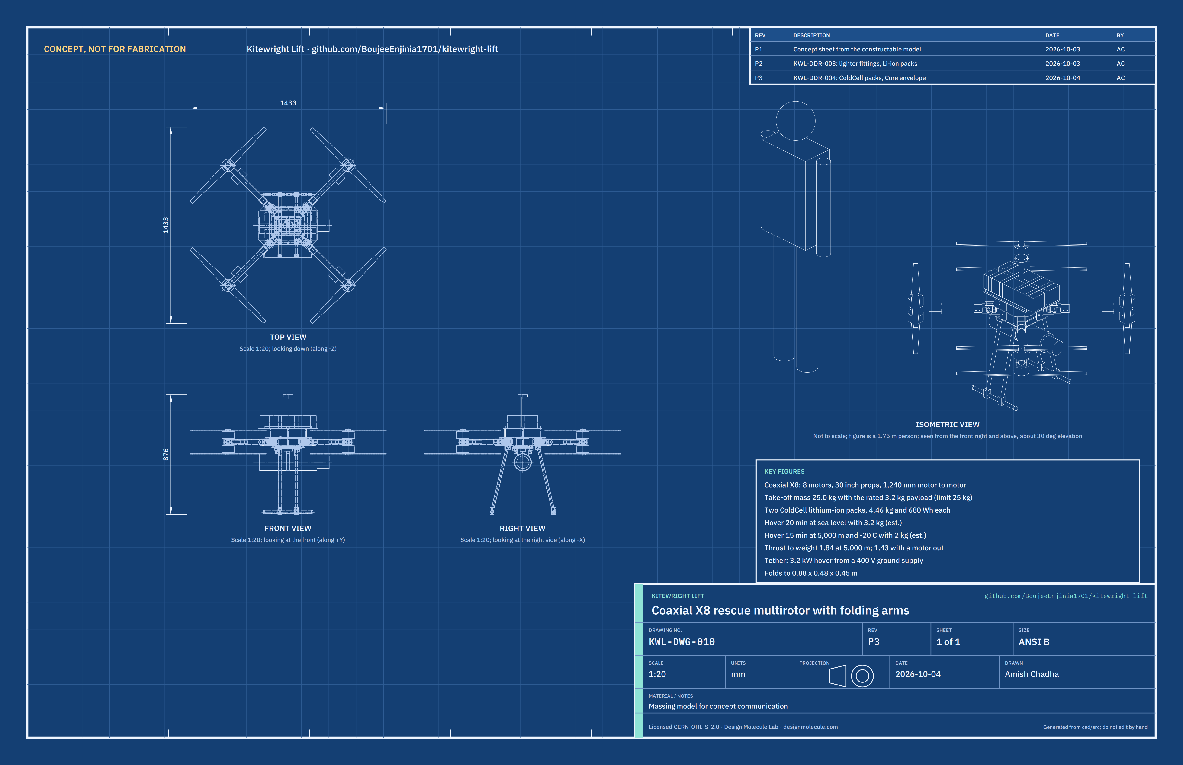
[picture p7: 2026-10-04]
media/concept-blueprint.png

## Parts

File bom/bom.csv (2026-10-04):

item | qty | spec | supplier | unit_cost_usd | make_buy | notes
1 Top hub plate | 1 | 3 mm carbon fibre sheet, 280 x 280 mm with the four corners cut square to the arms (66 mm chamfer faces); 16 M4 clearance holes for the hinge blocks, 4 M3 holes for the spacers, 30 mm cable hole at the centre; for the Kitewright Core lid below it (decision 10A): a 26 mm hole for the GNSS mast boss, three 12 mm holes over the SMA bulkheads and a 20 mm hole over the safety switch | Carbon sheet supplier with a CNC routing service | 45.00 | make | Indicative; 0.34 kg from cad/src/model.py; KWL-DWG-101; the four Core holes add about 2 min of routing at no extra price
2 Bottom hub plate | 1 | 3 mm carbon fibre sheet, 280 x 280 mm, same outline as item 1; the Kitewright Core's lower deck (decision 10A): four 4.3 mm holes on the 220 x 130 mm pattern and a 200 x 112 mm opening for the Core lid; eight M4 holes for the gear top blocks | Carbon sheet supplier with a CNC routing service | 45.00 | make | Indicative; 0.24 kg (0.35 kg before the opening); KWL-DWG-102; the opening replaces the damper, rail, socket and cable holes at the same routing price
3 Hub spacers and deck standoffs | 8 | Aluminium round standoff 8 mm, M3 female both ends: four 60 mm between the hub plates and four 60 mm from the hub to the deck (25 mm before decision 8A raised the deck above the upper rotors) | Hobby or industrial fastener supplier | 2.50 | buy | Indicative; one long M3 screw runs through each pair
4 Arm hinge blocks | 4 | 6061-T6 aluminium machined from 50 x 50 mm bar, 90 x 46 x 60 mm: bolting end with four M4 tapped holes top and bottom and a lightening pocket; 32 mm clevis slot with 7 mm cheeks; 8 mm pivot hole and 8 mm lock-pin hole; 10 x 10 mm stop bridge across the cheek tops; lightened (decision 34A): side pockets in the bolting end, a window through both cheeks, cheek corners cut below and under the bridge, 4 to 5 mm walls round every hole | Local machine shop or online CNC service | 60.00 | make | Indicative; 0.19 kg each (0.29 before decision 34A); USD 12 more each for the extra pockets (about 10 min of CNC time at a job-shop rate of about USD 70 an hour); KWL-DWG-104; carries the thrust of one arm through the stop bridge
5 Arm root fittings | 4 | 6061-T6 aluminium machined in one piece: tongue 65 x 30 x 48 mm with 8 mm pivot and lock holes and a 22 x 24 mm window; collar 48 mm OD x 50 mm with a 40.2 mm bore; two 5.2 mm cross holes; lightened (decision 34A): window 22 x 28 mm and side pockets 12.5 mm deep each side leaving a 5 mm web and 5 mm bosses round the pivot and lock holes | Local machine shop or online CNC service | 54.00 | make | Indicative; 0.24 kg each (0.29 before decision 34A); USD 12 more each for the pockets (about 10 min of CNC time at about USD 70 an hour); KWL-DWG-105
6 Arm tubes | 4 | Roll-wrapped carbon tube 40 mm OD x 36 mm ID, cut to 405 mm (410 before decision 34A shortened the motor clamp); three 5.2 mm cross holes | Carbon tube supplier | 24.00 | make | Indicative; cut from 1 m lengths; bonded and bolted into items 5 and 7
7 Motor mounts | 4 | 6061-T6 aluminium split clamp 40 x 60 x 52 mm (shortened from 50 mm by decision 34A) for a 40 mm tube, two halves on four M4 x 55 bolts; each outer face tapped for the motor (four M4 on a 35 mm circle, to suit the motor bought); one 5.2 mm cross hole | Local machine shop or online CNC service | 44.00 | make | Indicative; 0.19 kg each (0.24 before decision 34A); USD 6 more each for the extra set-up of the shorter clamp (estimate); KWL-DWG-107; motor hole pattern confirmed when the motors are bought
8 Hinge pivot bolts | 4 | Stainless M8 shoulder bolt, 8 mm x 50 mm shoulder, with nyloc nut and two washers | Fastener supplier | 4.00 | buy | Indicative
9 Arm lock pins | 4 | 8 mm ball-lock quick-release pin, about 55 mm grip, ring handle, lanyard and red flag | Industrial tooling supplier | 16.00 | buy | Indicative; tethered to the hinge block by the lanyard
10 Motors | 8 | Brushless outrunner for 30 inch propellers: about 100 KV, 12S to 16S, about 450 g, maker's figure about 10 kg static thrust with a 30 x 10 propeller at 51 V; 4 x M4 base on a 35 mm circle | Drone propulsion maker (heavy-lift class) | 185.00 | buy | Indicative; to be proven on AltiRig at 5000 m density (R3)
11 Motor controllers | 8 | ESC rated 16S (67 V), 80 A continuous, CAN or DShot with telemetry, IP-rated potting preferred, about 110 g | Drone propulsion maker | 85.00 | buy | Indicative; strapped to the arm tube
12 Folding propellers | 8 | 30 x 10 carbon folding propeller with hub, 4 CW and 4 CCW (upper and lower rotors turn opposite ways) | Drone propulsion maker | 55.00 | buy | Indicative; balanced before fitting
13 Gear top blocks | 4 | 6061 aluminium machined from 30 x 40 mm bar, 25 mm tall, with a 20.1 mm socket at 13.4 degrees and two M4 tapped holes | Local machine shop or online CNC service | 18.00 | make | Indicative; KWL-DWG-108
14 Skid blocks | 4 | 6061 aluminium machined, 30 x 30 x 50 mm, with a 20.1 mm cross bore for the skid, a 20.1 mm socket at 13.4 degrees for the strut and an M4 cross bolt | Local machine shop or online CNC service | 18.00 | make | Indicative; KWL-DWG-108
15 Gear struts | 4 | Carbon tube 20 mm OD x 17 mm ID, cut to 475 mm | Carbon tube supplier | 8.00 | make | Indicative; bonded into items 13 and 14
16 Skids with end caps | 2 | Carbon tube 20 mm OD x 17 mm ID, cut to 340 mm, with two 24 mm rubber end caps each | Carbon tube supplier | 9.00 | make | Indicative
17 Battery deck | 1 | 2 mm carbon fibre sheet 430 x 280 mm (330 x 290 x 3 before decision 8A), corners chamfered 35 mm; four 120 x 60 mm lightening windows under the pack ends, eight 30 x 4 mm strap slots, six M4 guide holes, four M3 standoff holes, 17 mm centre hole | Carbon sheet supplier with a CNC routing service | 55.00 | make | Indicative; 0.28 kg from cad/src/model.py; KWL-DWG-103; price scaled by area from the 3 mm sheet price of v0.2 (USD 50 for 330 x 290 mm), 2 mm sheet at about 70 % of 3 mm per area, plus about USD 10 of routing for the windows
18 Pack guides | 2 | Aluminium angle 15 x 15 x 1.5 mm, cut to 340 mm, three M4 holes | Metal stockholder | 4.00 | make | Indicative; same stock price for the lighter angle
19 Pack straps | 4 | 25 mm cam-buckle strap with rubber backing, 900 mm, round both packs | Outdoor or drone supplier | 7.00 | buy | Indicative; USD 1 more for the longer strap (same supplier, priced by length)
20 GNSS mast | 1 | Carbon 16 mm GNSS mast, 230 mm, with a foot clamp; carries the Core GNSS puck | Drone parts supplier | 25.00 | buy | Indicative
21 Kitewright Core stack | 1 | Kitewright Core to KWC-DWG-001 Rev P2: 240 x 150 mm carbon plate hung under the bottom hub plate on four 8 mm corner spacers (M4, 220 x 130 mm), lid 168 x 92 mm up through the 200 x 112 mm opening; autopilot, GNSS and compass, radios, power board; 0.99 kg (Core R9) | Kitewright Core design (sibling repository) | 950.00 | buy | Indicative; Lift's share of the core; the Core's GNSS receiver goes on Lift's deck mast (item 20) and its three antennas on extension leads (item 24), as the interface table allows
22 Core payload mount | 1 | Kitewright Core payload rail (spacer bars, lips, front stops, pin blocks), two locking pins and the DS-014 pigtail, under the Core plate | Kitewright Core design (sibling repository) | 100.00 | buy | Indicative; part of the Core kit; mass included in item 21
23 ColdCell packs (lithium-ion variant for Lift) | 2 | ColdCell lithium-ion pack for Lift as drawn on CCL-DWG-002 (decision 8A): 14S3P of 21700 high-power cells (4.5 Ah, 45 A), 410 x 94 x 94 mm, 4.46 kg, 680 Wh, 50.4 V nominal (42.0 to 58.8 V), AS150 lead; charge blocked below 5 C, heater cut-outs, a fuse wire on every cell; charged in ColdCell's fire-resistant charging box | ColdCell design (sibling repository) | 762.00 | buy | Indicative; ColdCell's estimate for each pack with its AS150 lead (CCL-CAL-001 K, bom/bom-lift-li-ion.csv); USD 134 more each than the USD 628 Lift assumed in v0.2
24 Power wiring | 1 | 10 AWG and 12 AWG silicone wire, AS150 connectors on every pack and bus lead (family interface, decision 10A), motor-lead extensions, spiral wrap, cable ties; the frame-to-Core power leads (Core decision 33B): 8 AWG silicone wire and four AS150 anti-spark halves soldered to the Core's pads; three 300 mm SMA extension leads that take the Core's antennas to the gear struts | Electronics supplier | 165.00 | buy | Indicative; about 0.80 kg; the frame-to-Core leads add USD 60 and about 0.12 kg (KWC line 21 moved here); the antenna leads add USD 15 and 0.03 kg (hobby RF supplier, about USD 5 each)
25 Fastener and bonding kit | 1 | Stainless M3, M4 and M5 screws, nyloc nuts and washers; medium threadlocker; structural epoxy for the tube joints | Fastener and adhesive supplier | 60.00 | buy | Indicative
26 Payload shoe (float release) | 1 | 6061-T6 plate 184 x 128 x 5 mm to KWC-DWG-106: 18 x 28 mm front notch, two 5.5 mm pin holes, four 4.5 mm holes for the saddles and release unit | Local machine shop or online CNC service | 30.00 | make | Indicative; KWL-DWG-109; payload only (not in R11); USD 5 less than the 240 x 124 x 6 mm plate it replaces (less stock and no lug)
27 Float saddles | 2 | PETG, 3D printed, 20 x 80 x 55 mm with a 121 mm round seat (inside the Core's 88 mm payload neck) | 3D printing service or makerspace | 5.00 | make | Indicative; payload only; USD 1 more for the taller print
28 Release unit | 1 | Servo-driven pin release rated 10 kg, PWM or DS-014 controlled, fails closed | Drone payload supplier | 45.00 | buy | Indicative; payload only
29 Float sling | 1 | 25 mm polyester webbing loop round the float with a sewn release loop | Sewn locally | 8.00 | make | Indicative; payload only
30 Rescue float and line bag | 1 | Closed-cell foam rescue float 120 mm x 420 mm (about 0.6 kg) with 30 m of 6 mm floating line in a throw bag; the line is never tied to the aircraft | Water rescue supplier | 75.00 | buy | Indicative; payload only
31 Payload shoe (tether module) | 1 | As item 26, drilled for four aluminium posts 8 mm x 34 mm that hang the converter below the payload neck | Local machine shop or online CNC service | 43.00 | make | Indicative; KWL-DWG-110; payload only; posts USD 2 each from a fastener supplier
32 Tether DC-DC converter | 1 | Isolated DC-DC converter, 380 to 420 V in, 51 V out, 4 kW, conduction cooled with fins, about 1.4 kg, 200 x 110 x 65 mm | Power electronics supplier | 950.00 | buy | Indicative; payload only
33 Tether breakaway connector | 1 | Two-pole, 600 V, 15 A, pull release at about 200 N | Connector supplier | 120.00 | buy | Indicative; payload only
34 Tether | 1 | 60 m: two 0.75 mm2 conductors, 600 V insulation, aramid strength member, about 25 g/m | Cable supplier | 360.00 | buy | Indicative; ground equipment
35 Ground power supply | 1 | 400 V DC fixed-voltage isolated supply, 4.5 kW, current limit, from a generator or the grid | Power electronics supplier | 1400.00 | buy | Indicative; ground equipment
36 Tether reel | 1 | Hand reel with a slip ring rated 600 V and 15 A, brake, 80 m capacity | Cable reel supplier | 450.00 | buy | Indicative; ground equipment
37 Ground safety set | 1 | Insulation monitor, emergency stop, residual-current protection and earthing kit for the ground supply | Electrical supplier | 180.00 | buy | Indicative; ground equipment
38 Payload plugs | 2 | DS-014 mating plug for each payload plate | Kitewright Core design (sibling repository) | 25.00 | buy | Indicative; payload only
39 ColdCell ground equipment | 1 | ColdCell pre-heat supply, 14S charger and fire-resistant charging box for the lithium-ion packs | ColdCell design (sibling repository) | 255.00 | buy | Indicative; ground equipment (not in R11); ColdCell's first-pack cost of USD 1,017 less the USD 762 pack (CCL-CAL-001 K)

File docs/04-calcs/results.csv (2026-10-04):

id | requirement | result | status
R1 | Maximum take-off mass | 24.98 kg with the rated payload of 3.2 kg; 21.78 kg ready to fly | Met on paper
R2 | Payload at sea level | Rated payload 3.2 kg (allowance 3.22 kg); float release 1.46 kg and tether module 3.13 kg both fit; thrust to weight 2.88 | Met on paper
R3 | Payload at altitude | Thrust to weight 1.84 at 5,000 m and -20 C with 2 kg (23.8 kg) | Met on paper
R4 | Hover time | 20.4 min at sea level with the rated payload (25.0 kg); 14.5 min with 2 kg at 5,000 m and -20 C | Met on paper at the rated payload; 5 kg no longer fits inside R1
R5 | Motor-out tolerance | Thrust to weight with one motor out 2.24 at sea level, 1.43 at 5,000 m | Met on paper
R6 | Wind | 18 N drag at 10 m/s; tilt 4.3 deg; position hold set by tuning | Met on paper (thrust); hold to be shown in flight
R7 | Tethered endurance | 3.20 kW hover on the tether; converter margin 1.25; tether drop 25 V | Met on paper
R8 | Float and line drop | Expected miss 2.2 m from 10 m (2 m hold, wind drift 3.3 m aimed off) | Met on paper
R9 | Transport | Folded 0.88 x 0.48 x 0.45 m; set-up about 9 min | Met on paper
R10 | Operating temperature | ColdCell heating about 58 Wh from the ground supply before take-off; parts rated -20 to +45 C; full-length hover flights to 27 C ambient under ColdCell's 50 C warning (decision 9A) | Met on paper (part ratings); flights shortened above 27 C ambient
R11 | Prototype cost | USD 6,627 for the aircraft excluding payloads | Over the value-engineering target by USD 1,627
value | mtow_r | 24.9816
value | payload_rated | 3.2000
value | ready_kg | 21.7816
value | packs_wh | 1360.8000
value | p_sl_r | 3208.7160
value | p_alt_2 | 3816.1923
value | t_sl_r | 20.3566
value | t_alt_2 | 14.5487
value | tw_alt | 1.8373
value | tw_out_alt | 1.4290
value | tether_ground_kw | 3.5886
value | tether_loss | 225.3685
value | p_tether | 3195.0901
value | cost_frame | 6627.0000
value | fold_x | 451.1341
value | fold_y | 480.0000
value | fold_z | 876.0000

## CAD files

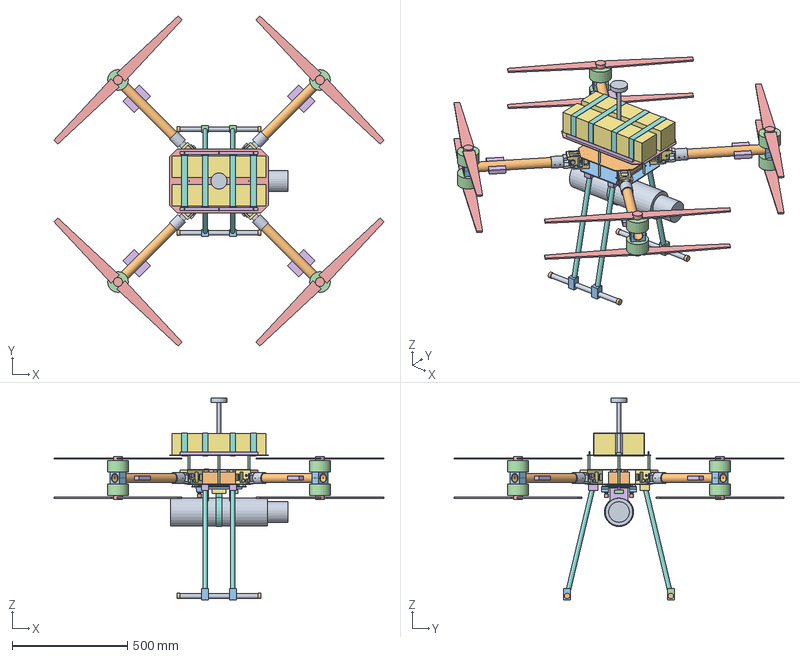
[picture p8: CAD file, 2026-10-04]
cad/step/kitewright-lift-assembly.step
1432.6 x 1432.6 x 876.0 mm

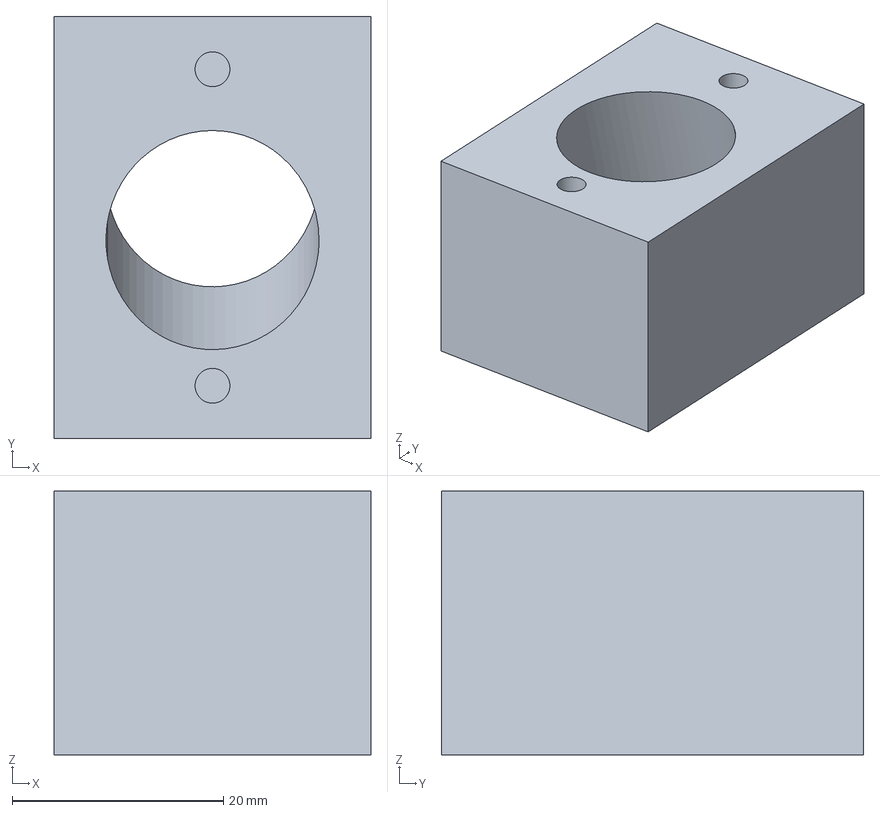
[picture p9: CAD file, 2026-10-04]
cad/step/kitewright-lift-gear-top-block.step
30.0 x 40.0 x 25.0 mm

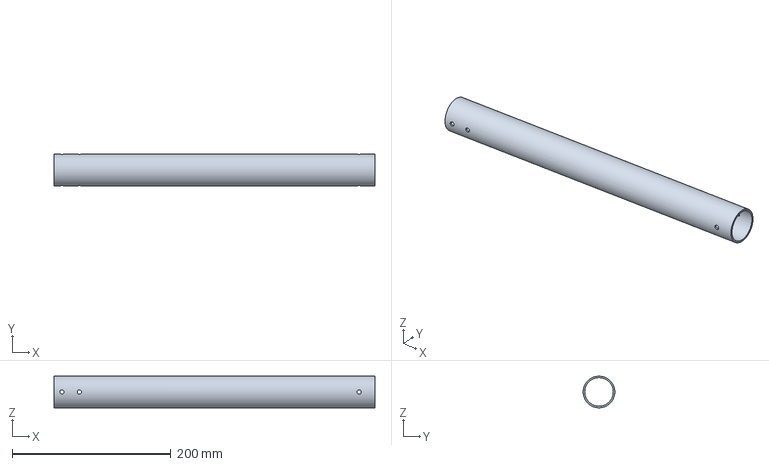
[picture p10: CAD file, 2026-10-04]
cad/step/kitewright-lift-arm-tube.step
405.0 x 40.0 x 40.0 mm

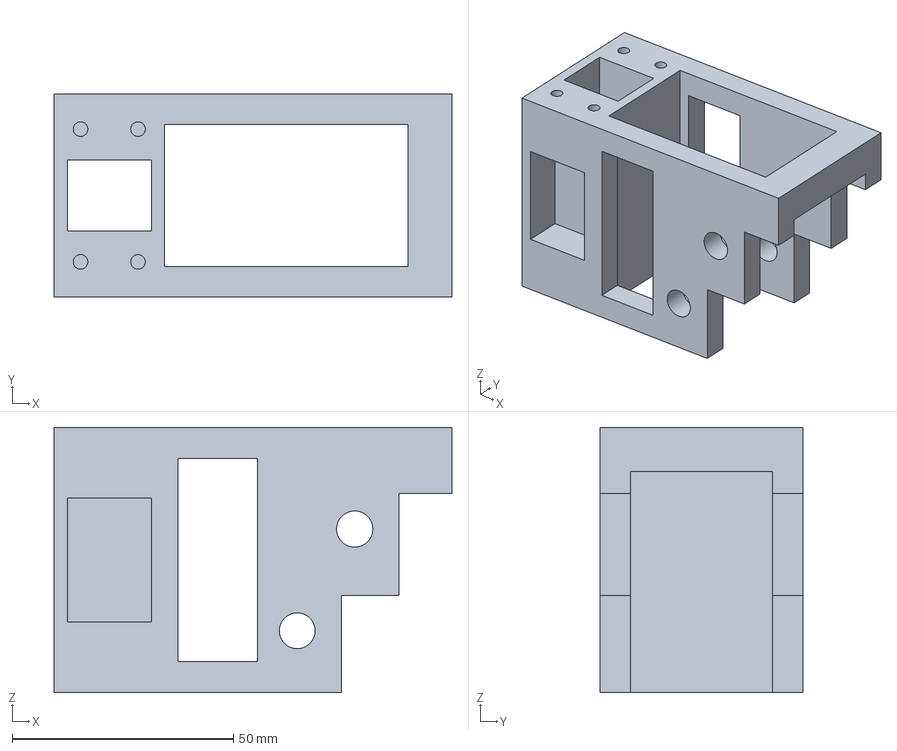
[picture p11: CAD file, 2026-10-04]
cad/step/kitewright-lift-hinge-block.step
90.0 x 46.0 x 60.0 mm

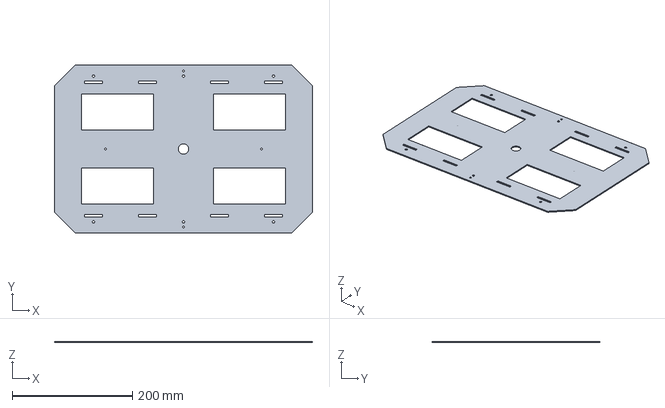
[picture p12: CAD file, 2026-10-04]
cad/step/kitewright-lift-battery-deck.step
430.0 x 280.0 x 2.00 mm

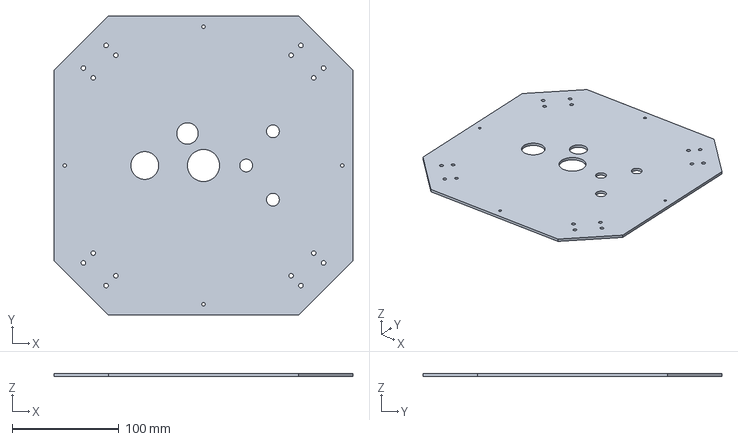
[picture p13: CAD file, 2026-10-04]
cad/step/kitewright-lift-hub-plate-top.step
280.0 x 280.0 x 3.00 mm

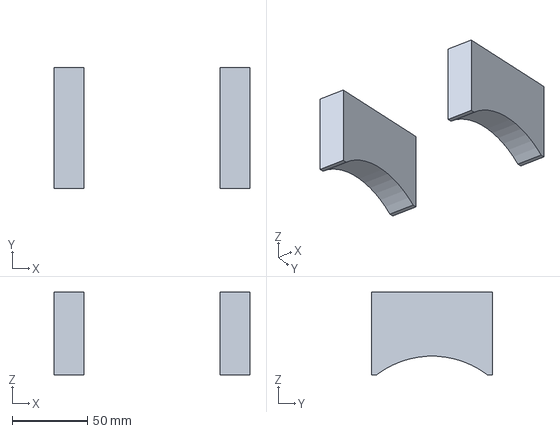
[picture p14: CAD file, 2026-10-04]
cad/step/kitewright-lift-float-saddle.step
130.0 x 80.0 x 55.0 mm

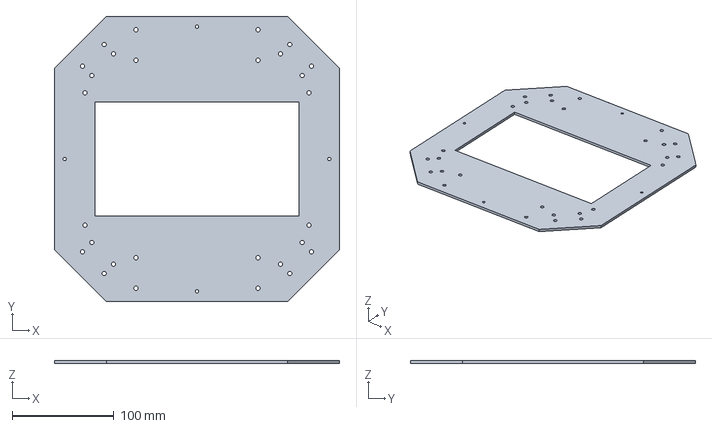
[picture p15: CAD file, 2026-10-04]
cad/step/kitewright-lift-hub-plate-bottom.step
280.0 x 280.0 x 3.00 mm

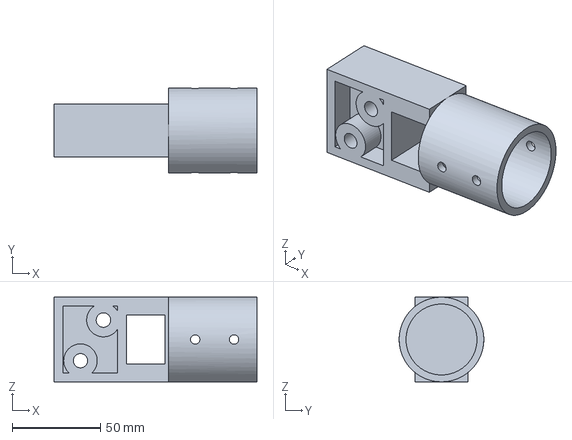
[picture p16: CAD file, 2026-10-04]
cad/step/kitewright-lift-arm-root-fitting.step
115.0 x 48.0 x 48.0 mm

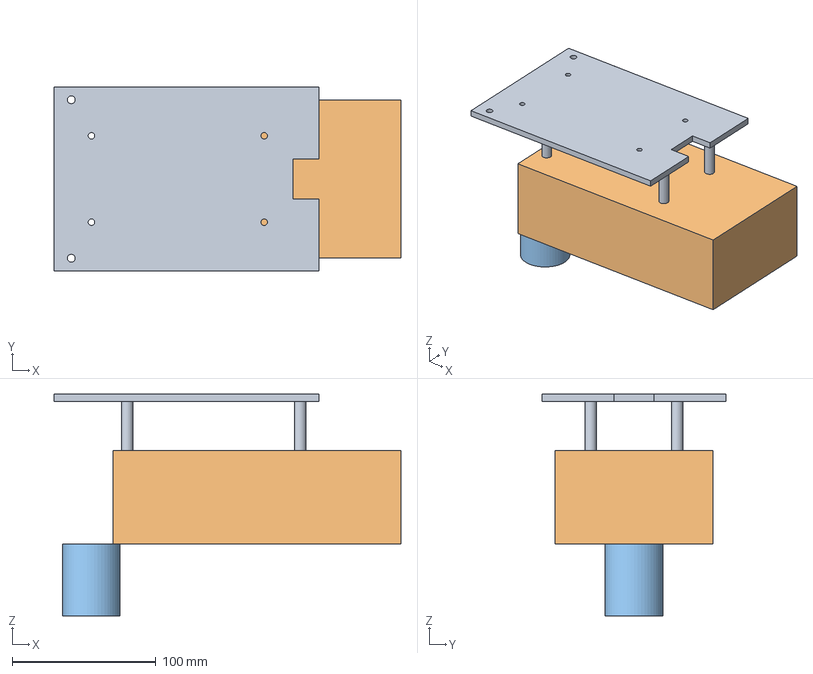
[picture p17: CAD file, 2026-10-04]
cad/step/kitewright-lift-tether-module.step
241.0 x 128.0 x 154.0 mm

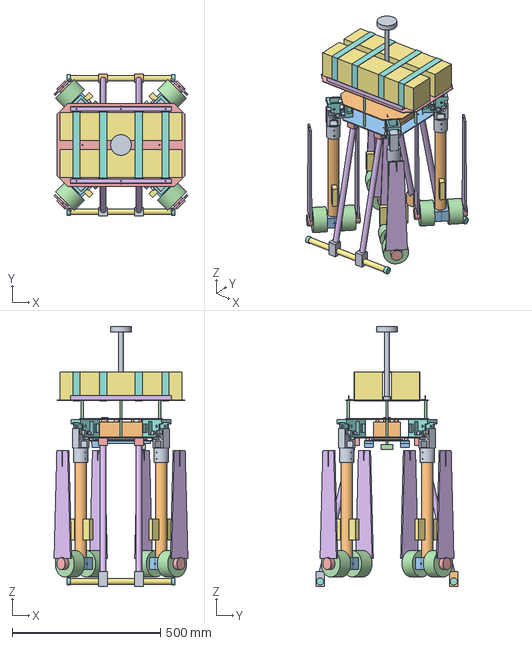
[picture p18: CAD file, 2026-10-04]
cad/step/kitewright-lift-folded.step
451.1 x 480.0 x 876.0 mm

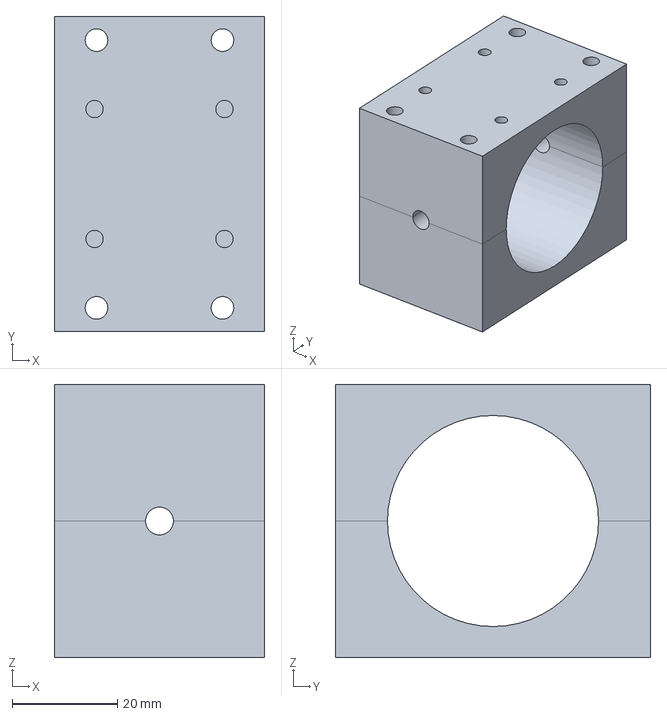
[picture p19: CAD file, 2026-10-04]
cad/step/kitewright-lift-motor-mount.step
40.0 x 60.0 x 52.0 mm

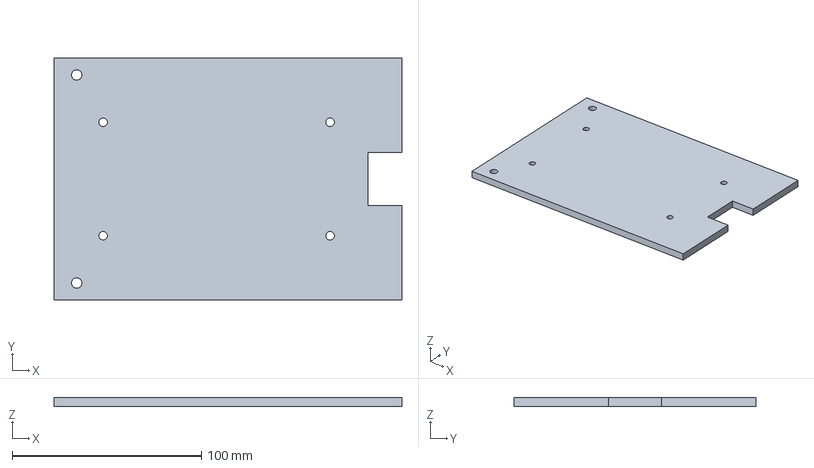
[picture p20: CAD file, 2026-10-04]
cad/step/kitewright-lift-payload-plate.step
184.0 x 128.0 x 5.00 mm

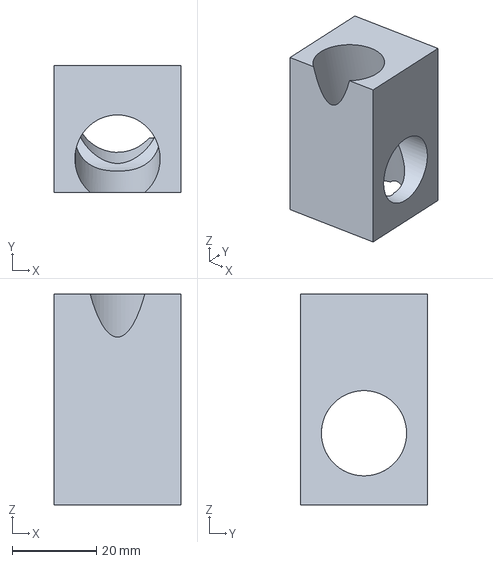
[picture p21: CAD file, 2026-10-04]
cad/step/kitewright-lift-skid-block.step
30.0 x 30.0 x 50.0 mm

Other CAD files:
cad/stl/kitewright-lift-arm-root-fitting.stl
cad/stl/kitewright-lift-arm-tube.stl
cad/stl/kitewright-lift-battery-deck.stl
cad/stl/kitewright-lift-float-saddle.stl
cad/stl/kitewright-lift-gear-top-block.stl
cad/stl/kitewright-lift-hinge-block.stl
cad/stl/kitewright-lift-hub-plate-bottom.stl
cad/stl/kitewright-lift-hub-plate-top.stl
cad/stl/kitewright-lift-motor-mount.stl
cad/stl/kitewright-lift-payload-plate.stl
cad/stl/kitewright-lift-skid-block.stl

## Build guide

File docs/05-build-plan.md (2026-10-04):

---
doc_id: KWL-BLD-001
title: Kitewright Lift prototype build plan
project: Kitewright Lift
doc_type: Build plan
version: "0.3"
status: Draft
date: '2026-10-04'
author: Amish Chadha
license: CERN-OHL-S-2.0
revisions:
- version: "0.1"
  date: '2026-10-03'
  author: Amish Chadha
  change: First build plan; design made constructable (KWL-DDR-002)
- version: "0.2"
  date: '2026-10-03'
  author: Amish Chadha
  change: Amish's decisions 34A and 35A (KWL-DDR-003); lighter hinge blocks, root fittings and motor clamps, lithium-ion ColdCell packs, frame-to-Core power leads (Core decision 33B)
- version: "0.3"
  date: '2026-10-04'
  author: Amish Chadha
  change: Amish's round-3 decisions 8A, 9A and 10A (KWL-DDR-004); ColdCell's packs as drawn on a re-sized, raised 2 mm deck; the Kitewright Core hung under the hub to the family envelope; payload shoes; AS150 everywhere; warm-weather operating note; sections 1, 2, 3.1, 3.3, 3.4, 3.5, 3.14 to 3.19, 3.22, steps 2, 3, 6, 11 to 15, first checks and safety stops
---

# Kitewright Lift prototype build plan

**Plan, not yet built.** How to build the first proof-of-concept prototype, component by component. Building and testing to it is TRL 4 work. Decisions still to be made are kept in the design decisions register (`docs/06-design-decisions.md`), not here.

> **Safety:** This plan builds a 25 kg class aircraft with eight 30 inch propellers, lithium-ion packs and a 400 V tether. Propellers can kill, lithium-ion packs can burn fiercely, and the tether carries a dangerous voltage. Every safety stop in section 6 is a hard stop: work does not go on until its conditions are true. Fly only where local rules allow, never near uninvolved people, and never carry or lift a person.

## 1. What you are building

Every component, pulled apart and numbered in build order

*Figure 1. Every component in build order. One of the four arms is shown pulled apart; the others are the same.*

Kitewright Lift is a coaxial eight-motor aircraft: a two-plate carbon hub with the Kitewright Core hung under it and its lid standing up inside, four carbon arms that fold down on machined aluminium hinges, a motor above and below each arm tip, a raised battery deck with two ColdCell packs on top, skid landing gear, and the Core's payload rail underneath. Two payloads are built with it: a line-and-float release and a tether power module with its ground set. Of the 39 lines in the parts list, 16 are made: carbon sheet routed to shape, carbon tube cut and drilled, aluminium fittings machined, two printed saddles and a sewn sling. The rest are bought, and the Core and the packs are built to their own designs. The parts are estimated at USD 6,627 for the aircraft and USD 3,976 for the payloads and ground equipment. Ready to fly it weighs about 21.8 kg, and it is rated to carry 3.2 kg inside its 25 kg take-off limit.

## 2. What changed to make it buildable

| Component | The concept had | The buildable design has | Why |
| --- | --- | --- | --- |
| Arm fold | Folding arms, no joint drawn | A machined hinge block at each hub corner: a slot for the arm's tongue, an 8 mm pivot bolt near the bottom, an 8 mm lock pin, and a stop bridge across the top | Lift presses the arm up against the bridge, so the arm cannot fold under power; the pin only stops it drooping |
| Arm root | Tube into the body | A one-piece aluminium fitting: a tongue in the hinge and a collar round the tube | A solid seat for the pivot and lock holes; the tube is bonded and bolted in |
| Hinge position | Not set | Pivot 180 mm from the centre and the plate corners cut at 162 mm | The folded arm otherwise cut into the bottom plate; now 6 mm clear |
| Central body | A body | Two 3 mm carbon plates 60 mm apart on the hinge blocks and four spacers; the Kitewright Core hung under the bottom plate, its lid up through a 200 x 112 mm opening | A light, stiff box, and the Core fitted to the family envelope that Range shares |
| Battery bay | Two heated packs | A 2 mm carbon deck on four 60 mm standoffs, above the upper rotors, two guides and four cam straps round both packs | ColdCell's 410 mm packs clear of the hinge pins and outside the rotor discs |
| Motor mount | Not drawn | A split clamp on the arm tip with a motor on its top face and one under it | Thick enough above the tube for the motor screws |
| Motor controllers | Not placed | Strapped to the arm near the tip | They fold with the arm; only two power leads cross the hinge |
| Landing gear | Wide gear | Four carbon struts in machined blocks, skids 450 mm apart, hub 500 mm up | Folded motors clear the skids and the ground |
| Payload bay | Clear space | The Core's rail, two locking pins and DS-014 pigtail; each payload on a payload shoe to KWC-DWG-106 | Every Kitewright payload fits Lift and Range the same way |
| Float release | A release | Payload shoe, printed saddles, a servo pin release and a sewn sling round a foam float | Bought release, simple made parts |
| Tether module | Converter and reel | Payload shoe, four posts, 4 kW converter, breakaway connector; ground supply, reel and safety set | Fits the same rail; parts if the tether snags |
| Fittings | Solid blocks | Pockets, windows and cut-away corners in each hinge block, side pockets and a window in each root fitting, and a 40 mm motor clamp | About a third of their first weight; 0.79 kg off the four arms |

## 3. Making the components

Sizes are in millimetres unless stated. Carbon sheet and tube: cut with a diamond or carbide tool, wear a dust mask and gloves, and seal cut edges with thin epoxy. Aluminium fittings are 6061-T6, machined by a machine shop or an online CNC service from the making sketches; deburr every edge.

### 3.1 Bottom hub plate

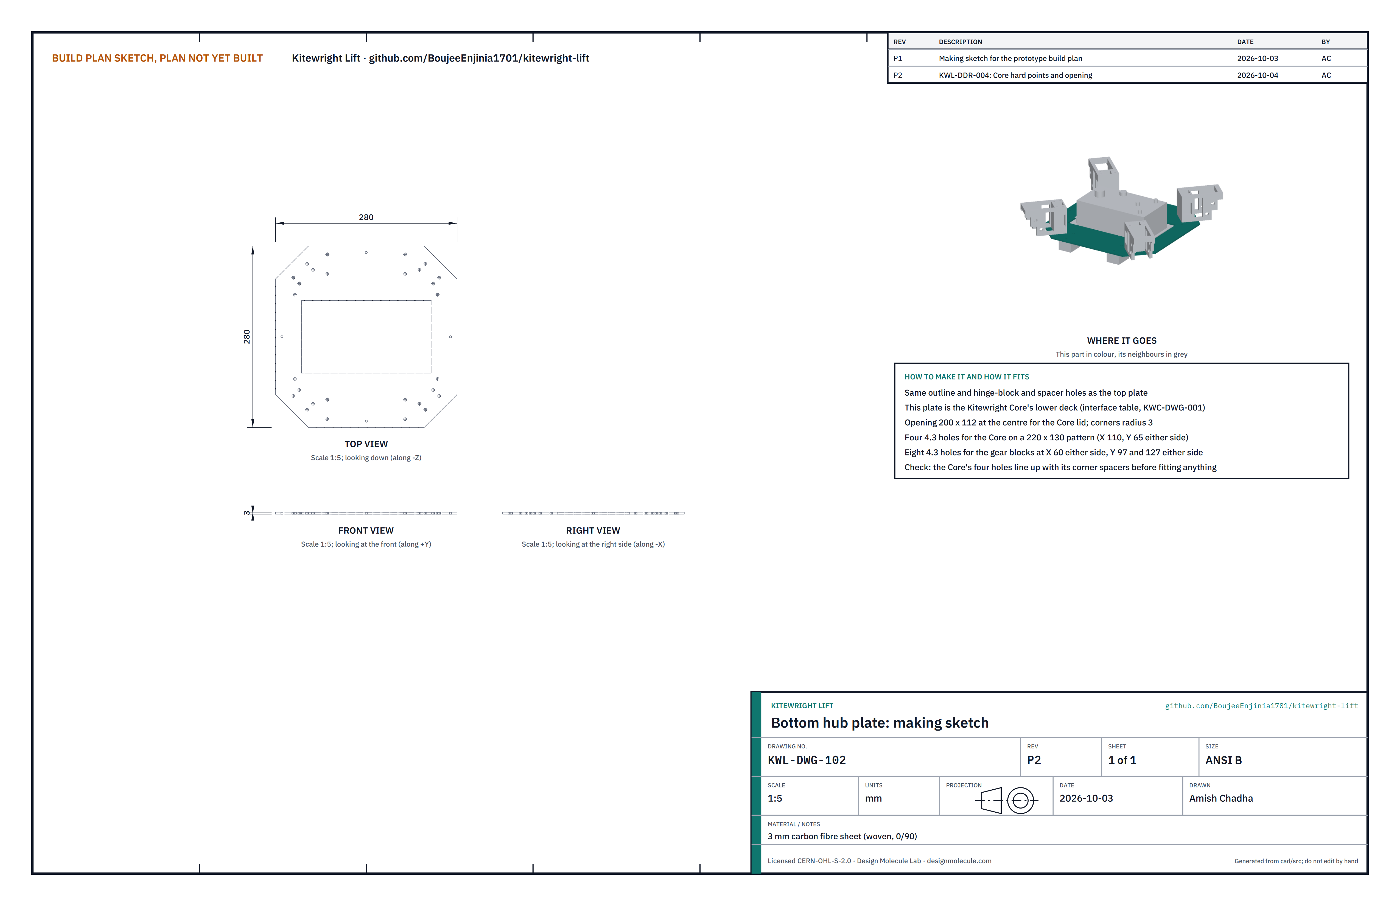
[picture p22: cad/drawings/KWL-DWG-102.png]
Making sketch: bottom hub plate


**What it is and what it is made from.** The floor of the hub: 3 mm woven carbon sheet, 280 mm square with each corner cut square to its arm.

**How to make it.**

1. Route the outline: 280 x 280 with each corner cut off by a 72 mm face, 162 mm from the centre measured along the diagonal.
2. Drill four 4.3 mm holes per corner for the hinge block: on the diagonal, 131 and 144 mm out from the centre, 15 mm either side.
3. Drill four 3.3 mm spacer holes 130 mm from the centre on the forward, back, left and right lines.
4. Cut the 200 x 112 mm opening for the Core's lid at the centre, and drill the Core's four 4.3 mm holes on a 220 x 130 mm pattern round it. This plate is the Core's lower deck (the Kitewright interface table).
5. Drill eight 4.3 mm holes for the gear top blocks: 60 mm either side of the centre line fore and aft, 97 and 127 mm out to each side.
6. Seal the edges, the opening's included.

**How it fits the parts next to it.** The hinge blocks and spacers sit on its top face; the gear top blocks and the Core hang under it, the Core on its own four 8 mm corner spacers. Every fixing is a screw through the plate into a tapped hole or a nut.

**Check before moving on.** Lay the top plate on it: every shared hole lines up; the Core's corner spacers line up with its four holes.

### 3.2 Arm hinge blocks (four)

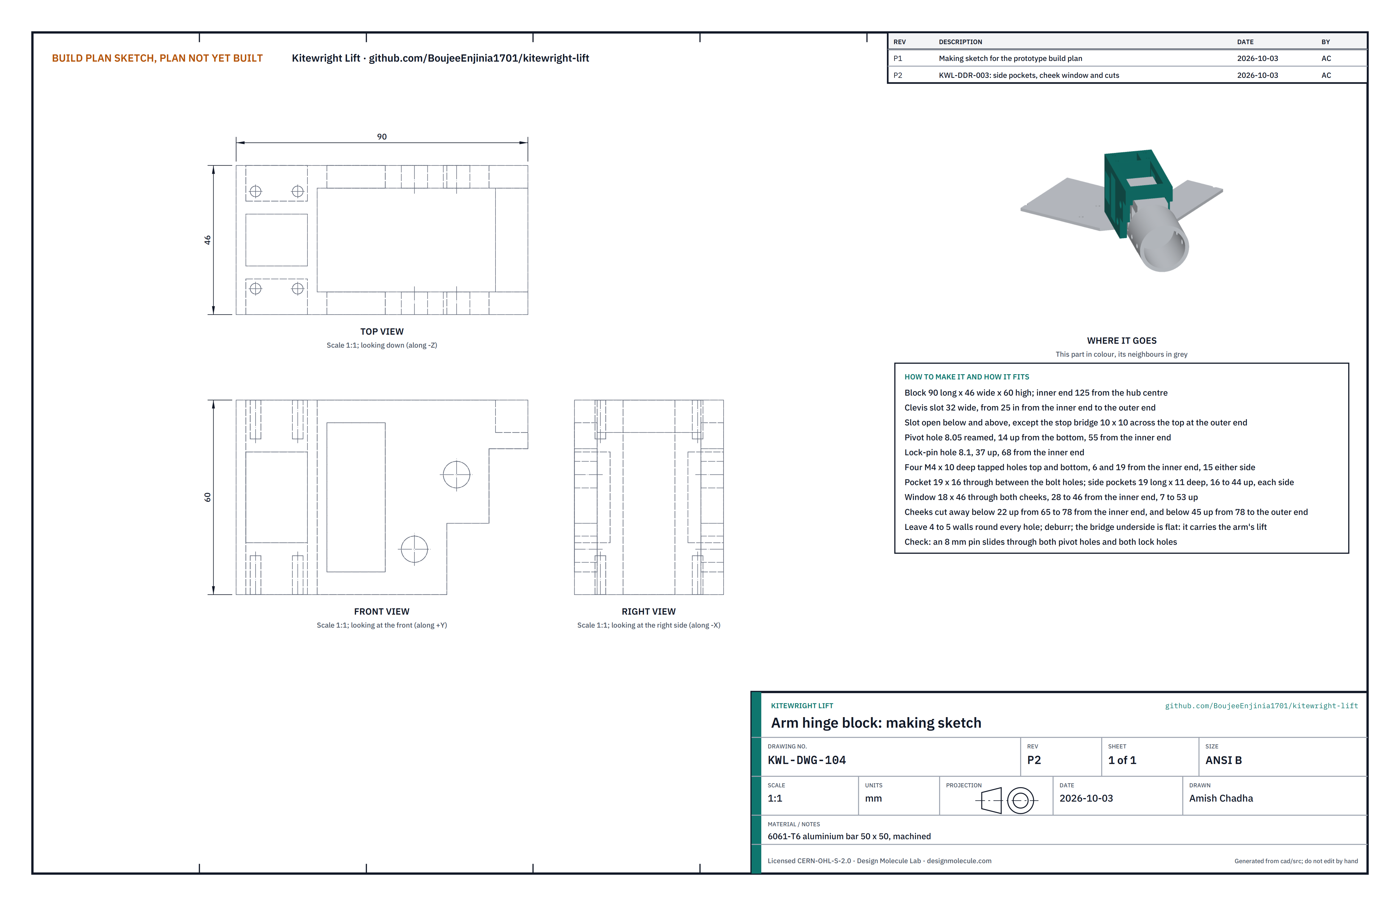
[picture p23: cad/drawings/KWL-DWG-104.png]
Making sketch: arm hinge block


**What it is and what it is made from.** The joint between hub and arm, and the spacer between the hub plates at each corner: 6061-T6 aluminium from 50 x 50 bar, 90 x 46 x 60 mm.

**How to make it.**

1. Square the block to 90 long, 46 wide, 60 high.
2. Mill the 32 mm slot from 25 mm in from the inner end to the outer end, open at the bottom, and open at the top except for a 10 x 10 mm bridge across the outer end.
3. Ream the 8.05 mm pivot hole through both cheeks, 14 mm up from the bottom and 55 mm from the inner end.
4. Drill the 8.1 mm lock-pin hole, 37 mm up and 68 mm from the inner end.
5. Tap four M4 holes 10 deep in the top face and four in the bottom face, 6 and 19 mm from the inner end, 15 mm either side.
6. Mill the 19 x 16 mm lightening pocket through between the tapped holes.
7. Mill a side pocket 19 mm long and 11 mm deep into each side of the bolting end, 16 to 44 mm up, so the tapped holes keep a solid floor.
8. Mill a window 18 x 46 mm through both cheeks, 28 to 46 mm from the inner end and 7 to 53 mm up.
9. Cut the cheeks away below 22 mm up from 65 to 78 mm from the inner end, and below 45 mm up from 78 mm to the outer end. This leaves a 15 mm rail along the top of each cheek to carry the bridge.
10. Leave at least 4 to 5 mm of metal round every hole. Deburr. The underside of the bridge must be flat and smooth: it carries the arm's lift.

**How it fits the parts next to it.**

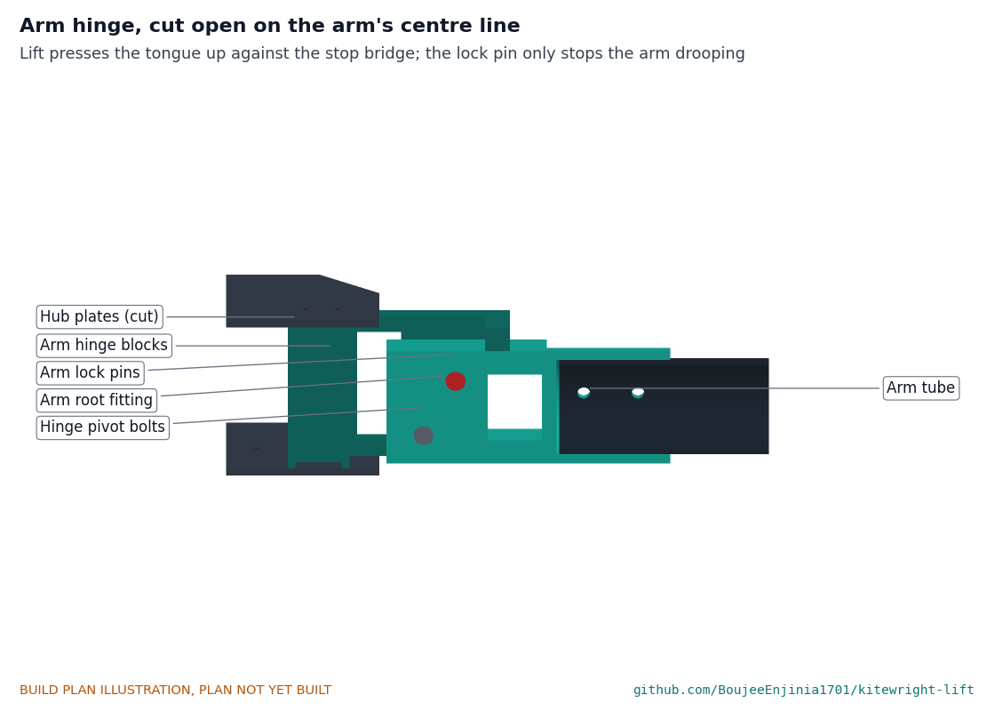
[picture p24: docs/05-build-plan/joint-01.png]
Close-up: arm hinge, cut open


*Figure 2. The arm hinge cut open on the arm's centre line. In flight the tongue's top presses up on the bridge; the pivot bolt is near the bottom; the lock pin stops the arm drooping.*

The block sits between the hub plates with its slot facing out along the diagonal. The arm's tongue fits the slot with 1 mm each side, turns on the pivot bolt, and in flight bears up against the bridge. The lock pin passes through both cheeks and the tongue.

**Check before moving on.** An 8 mm pin slides through both pivot holes and both lock holes in one line.

### 3.3 Top hub plate

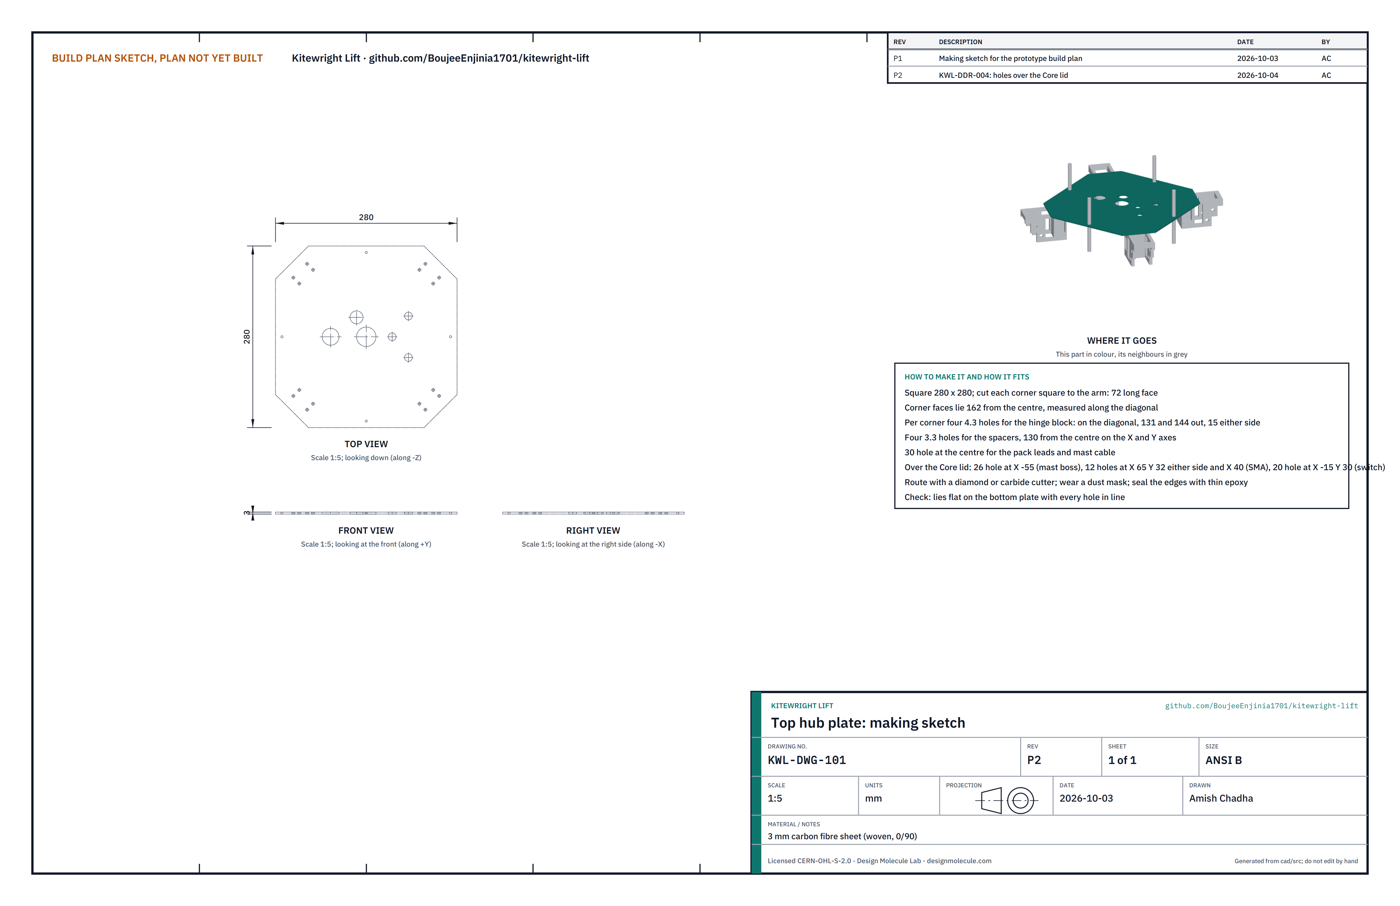
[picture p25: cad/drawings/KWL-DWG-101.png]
Making sketch: top hub plate


**What it is and what it is made from.** The roof of the hub, 3 mm carbon sheet, the same outline as the bottom plate.

**How to make it.**

1. Route the same outline as the bottom plate.
2. Drill the same hinge-block and spacer holes.
3. Drill a 30 mm hole at the centre for the pack leads and the mast cable.
4. Over the Core's lid: a 26 mm hole 55 mm behind the centre for its GNSS mast boss, three 12 mm holes over its SMA bulkheads (65 mm ahead, 32 mm either side, and 40 mm ahead on the centre line) and a 20 mm hole over its safety switch (15 mm behind, 30 mm to the left).
5. Seal the edges.

**How it fits the parts next to it.**

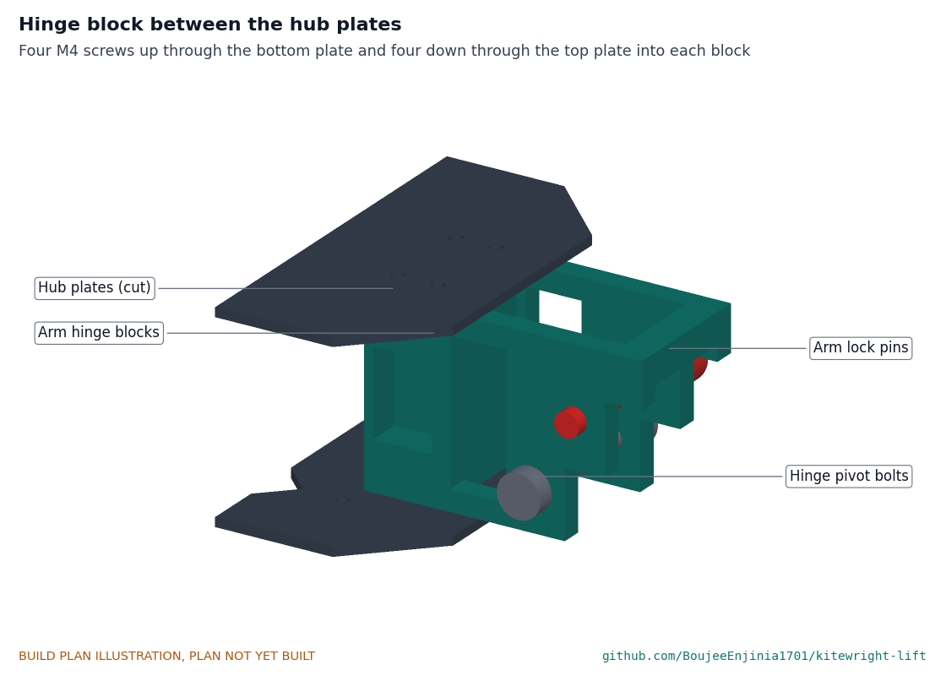
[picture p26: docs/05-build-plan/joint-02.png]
Close-up: hinge block between the hub plates


*Figure 3. Each hinge block is held by four M4 screws up through the bottom plate and four down through the top plate.*

**Check before moving on.** It lies flat on all four hinge blocks and spacers with no rocking.

### 3.4 Hub spacers and deck standoffs (bought)

Buy eight 60 mm aluminium round standoffs, 8 mm across, M3 inside both ends. Four hold the hub plates apart beside the Core's lid; four carry the battery deck high enough that its underside clears the upper rotor blades by 9 mm. One long M3 screw through the deck, a standoff, the top plate and a spacer ties each stack.

### 3.5 Kitewright Core (built to the Core design)

Build the Kitewright Core, with its rail, two locking pins and DS-014 pigtail, to the Kitewright Core build plan (KWC-BLD-001). Lift takes it to the family mounting envelope (the Kitewright interface table, 2026-10-04): the Core plate hangs under the bottom hub plate on its four 8 mm corner spacers with four M4 screws on the 220 x 130 mm pattern, and its lid stands 55 mm up through the 200 x 112 mm opening into the hub, its mast boss, SMA bulkheads and switch reaching up into holes in the top plate. Lift has no room for the Core's own antennas and mast above the lid: the Core's GNSS receiver goes on Lift's deck mast (section 3.16) and its three antennas on 300 mm SMA extension leads clipped to the gear struts, pointing down. The Core comes with solder pads and a strain-relief bar but no power leads; Lift supplies them (section 3.17a). It weighs 0.99 kg.

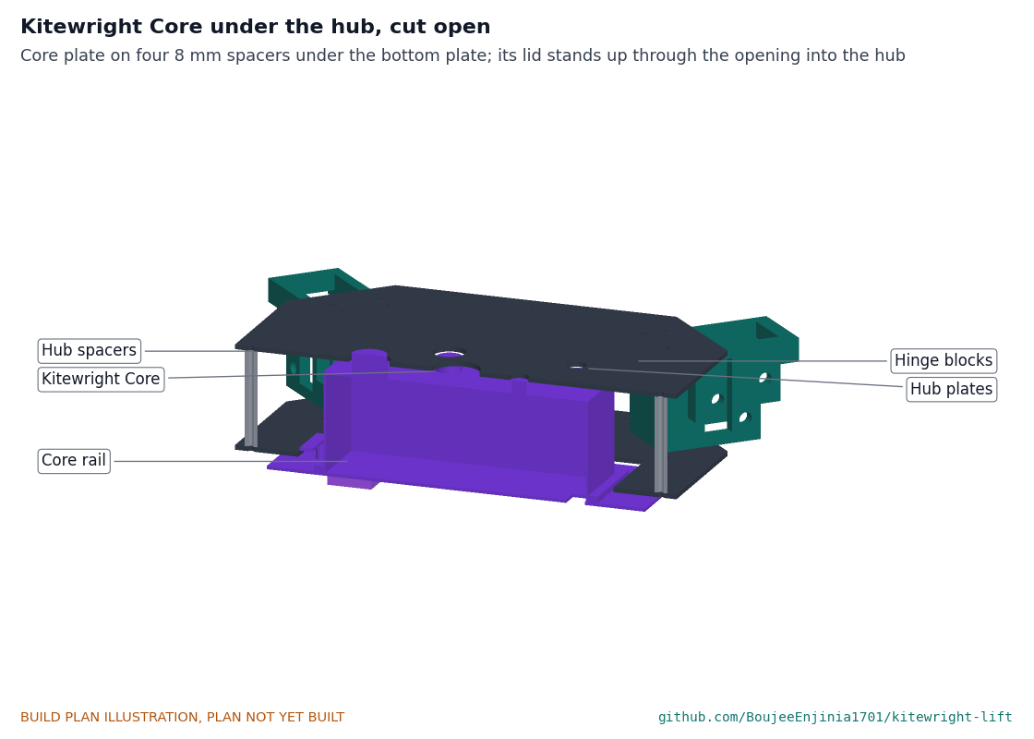
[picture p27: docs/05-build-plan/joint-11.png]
Close-up: the Kitewright Core under the hub, cut open


*Figure 4. The Core plate on its 8 mm spacers under the bottom plate, its lid standing up through the opening into the hub between the spacers and hinge blocks.*

### 3.6 Gear top blocks (four)

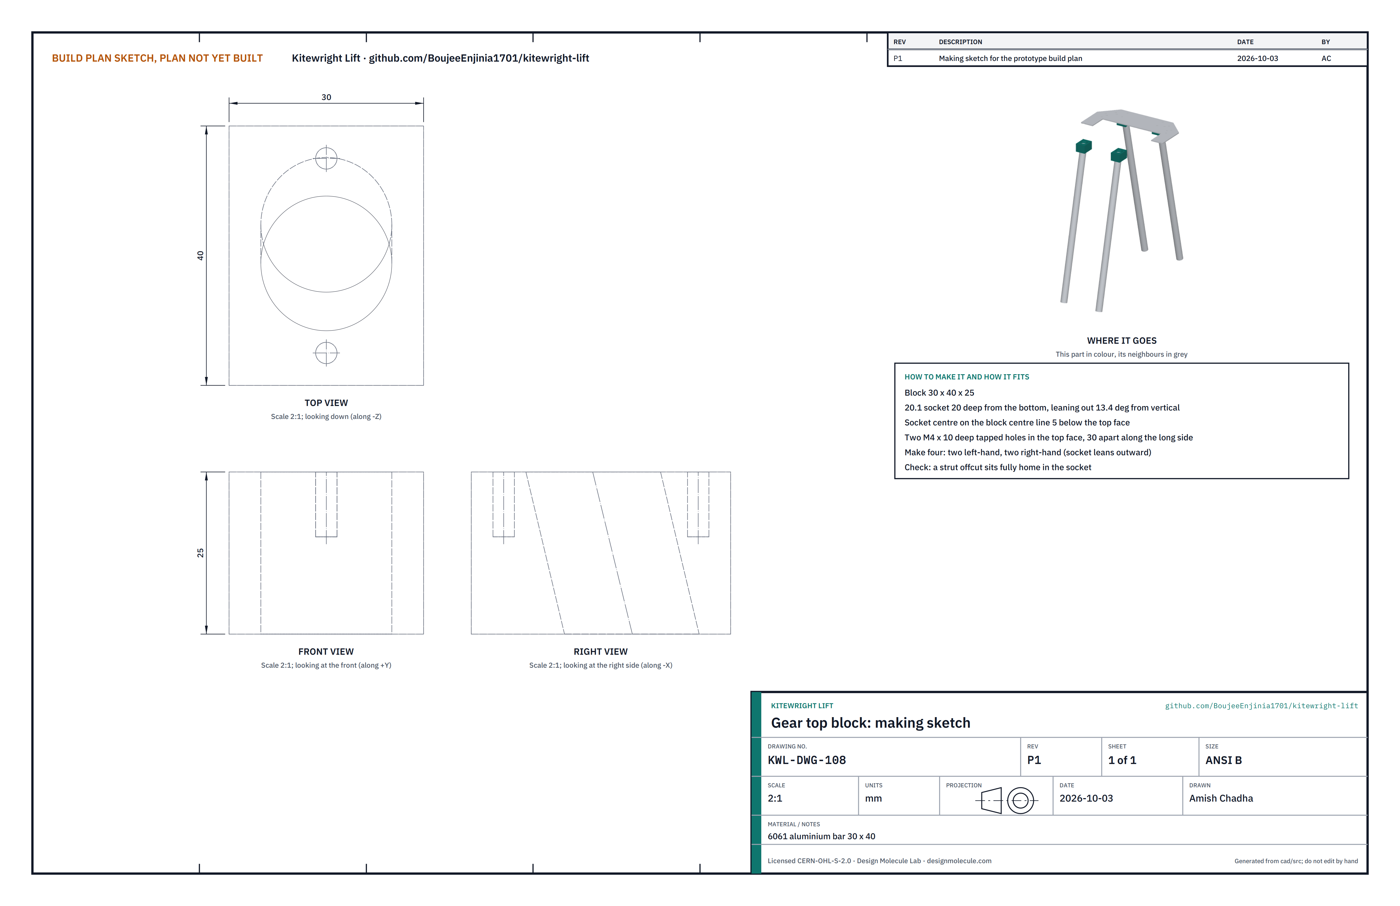
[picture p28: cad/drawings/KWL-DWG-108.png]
Making sketch: gear top block


**What it is and what it is made from.** The fixing that holds each gear strut under the hub: 6061 aluminium, 30 x 40 x 25 mm.

**How to make it.**

1. Square the block.
2. Bore a 20.1 mm socket 20 mm deep from the bottom, leaning outward 13.4 degrees from vertical, its centre on the block's centre line 5 mm below the top face.
3. Tap two M4 holes 10 mm deep in the top face, 30 mm apart.
4. Make two left-hand and two right-hand, so each socket leans outward.

**How it fits the parts next to it.**

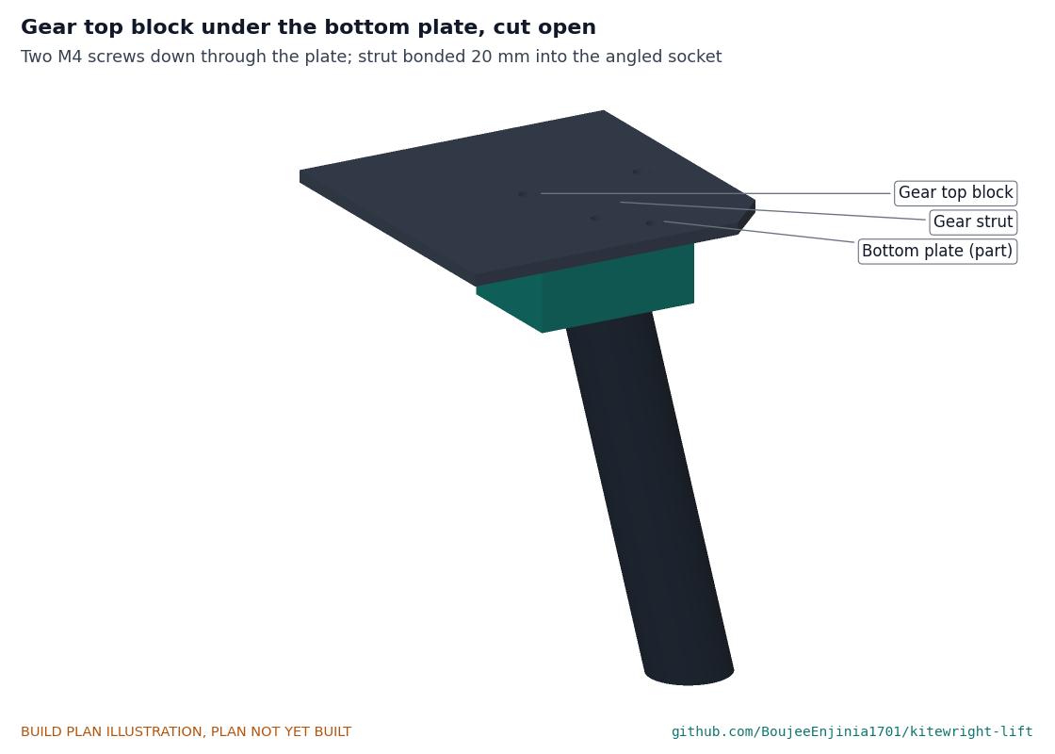
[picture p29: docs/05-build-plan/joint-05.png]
Close-up: gear top block


*Figure 5. Two M4 screws down through the bottom plate hold the block; the strut is bonded into its socket.*

**Check before moving on.** A strut offcut sits fully home in the socket.

### 3.7 Skid blocks (four)

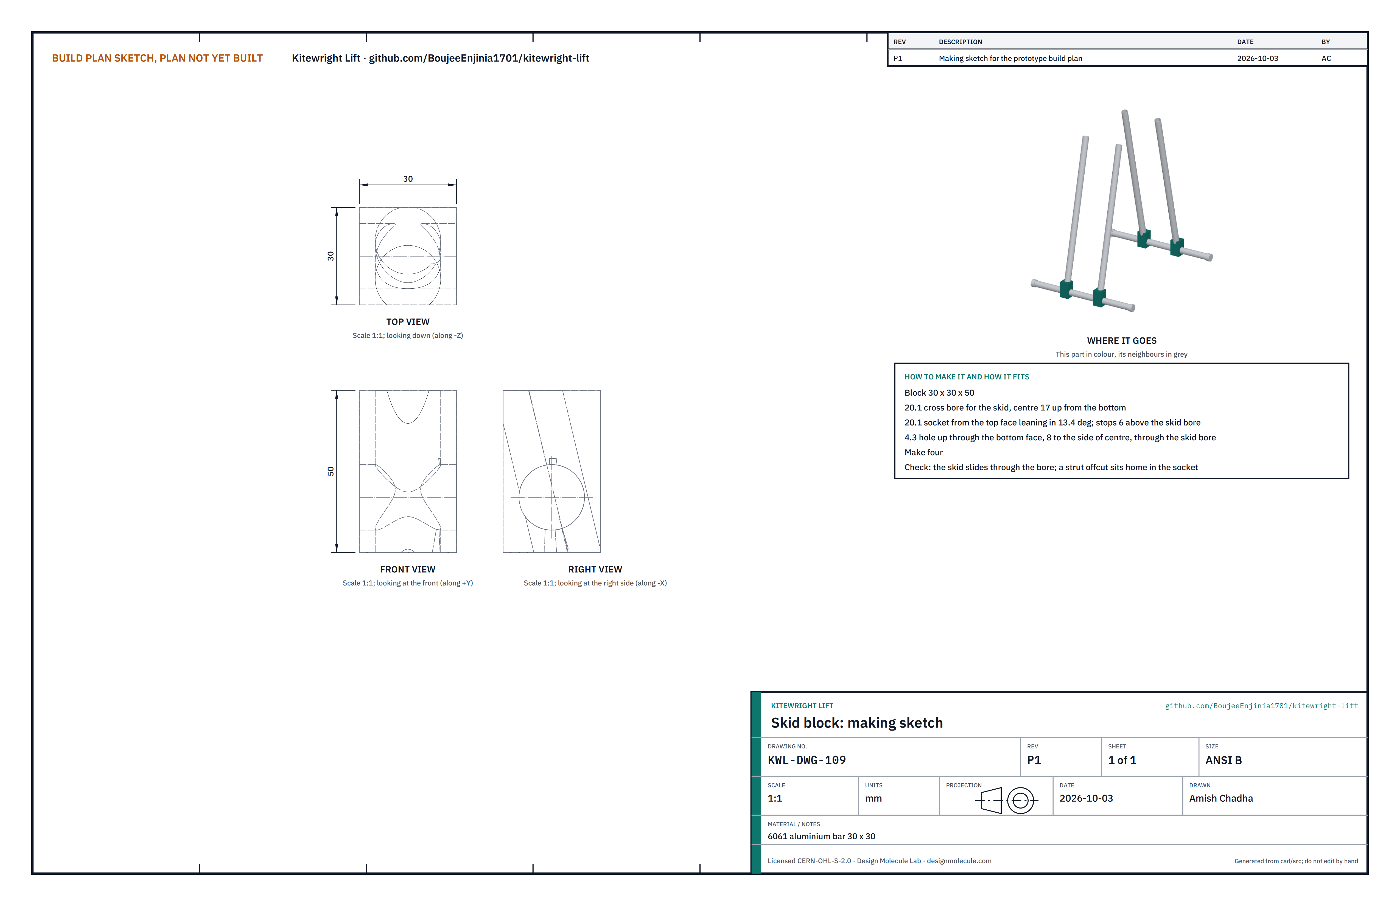
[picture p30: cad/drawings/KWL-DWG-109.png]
Making sketch: skid block


**What it is and what it is made from.** The foot of each strut, where it meets the skid: 6061 aluminium, 30 x 30 x 50 mm.

**How to make it.**

1. Square the block.
2. Bore the 20.1 mm cross bore for the skid, its centre 17 mm up from the bottom.
3. Bore the 20.1 mm strut socket down from the top face, leaning inward 13.4 degrees, stopping 6 mm above the skid bore.
4. Drill a 4.3 mm hole up through the bottom face, 8 mm to the side of centre, through the skid bore.

**How it fits the parts next to it.**

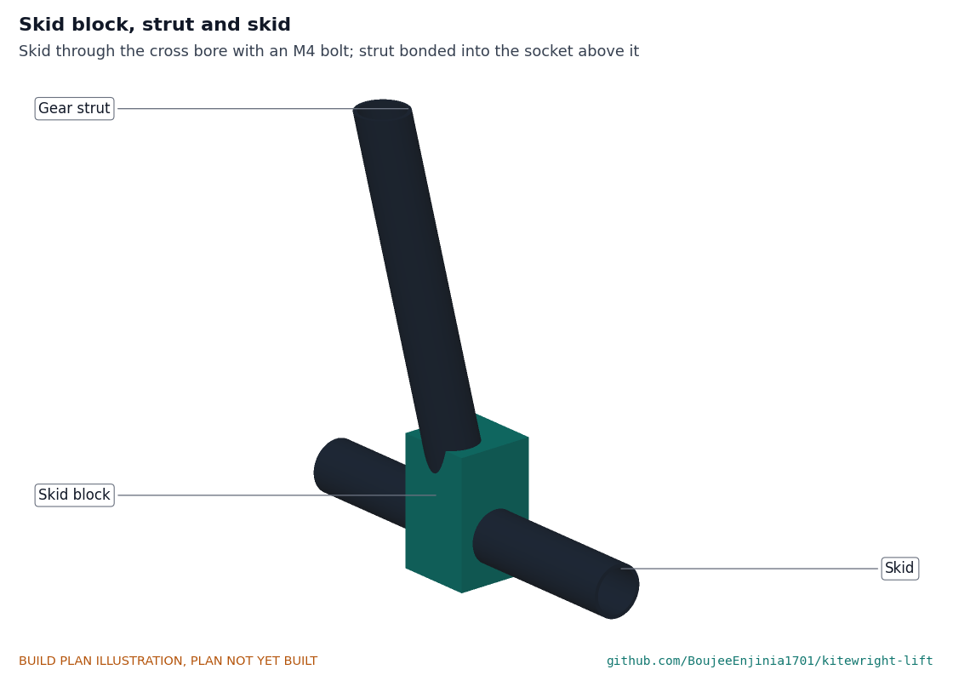
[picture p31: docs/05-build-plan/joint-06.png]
Close-up: skid block, strut and skid


*Figure 6. The skid passes through the cross bore and is held by an M4 bolt; the strut is bonded into the socket above it.*

**Check before moving on.** The skid slides through the bore and a strut offcut sits home in the socket.

### 3.8 Gear struts and skids

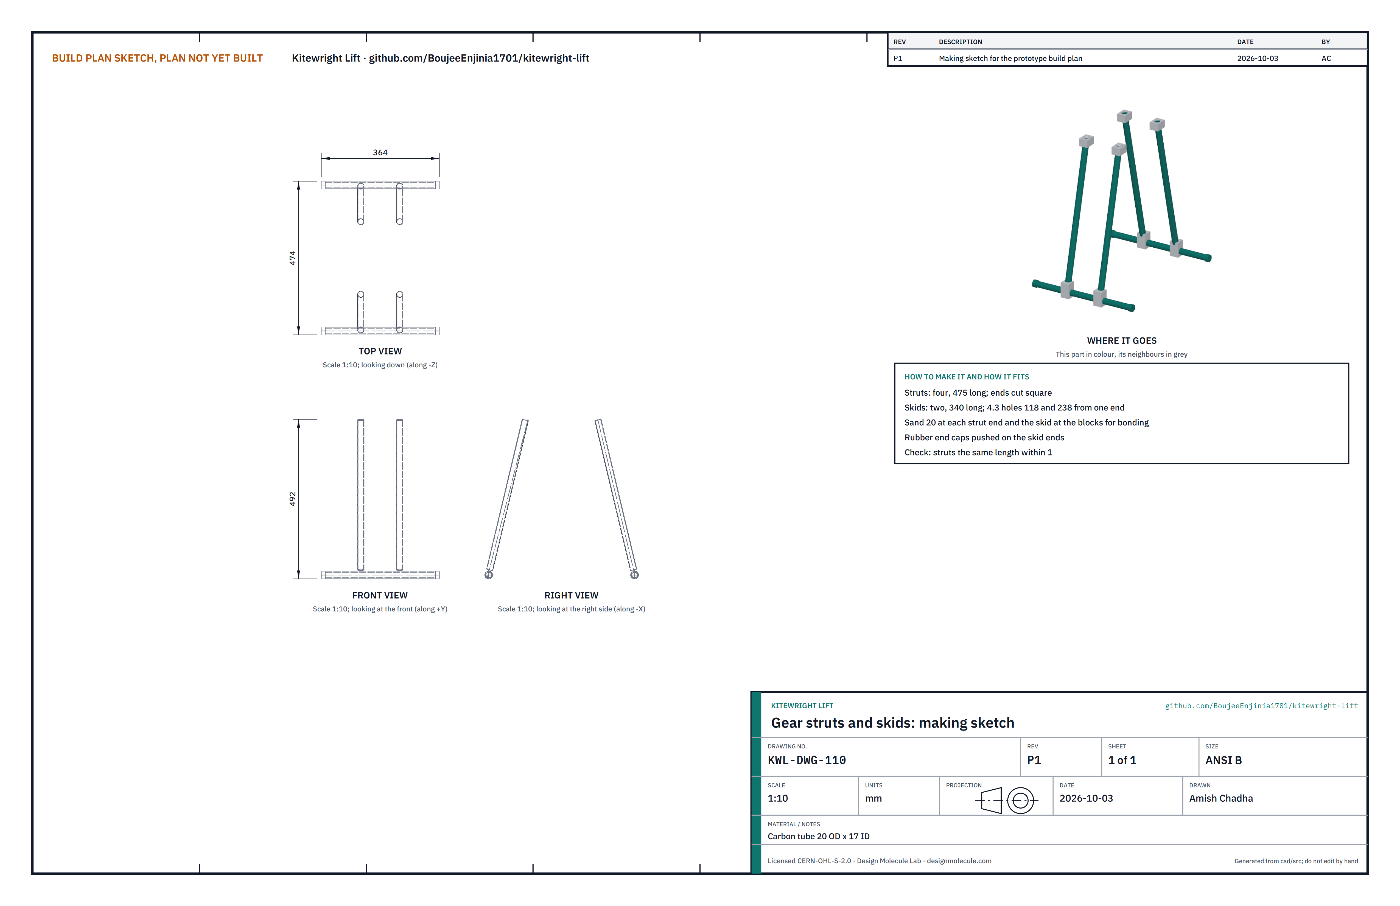
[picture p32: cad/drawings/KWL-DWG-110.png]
Making sketch: gear struts and skids


**What it is and what it is made from.** Carbon tube 20 mm across, 17 mm inside.

**How to make it.**

1. Cut four struts 475 mm long and two skids 340 mm long; square the ends.
2. Drill each skid with two 4.3 mm holes, 118 and 238 mm from the same end.
3. Sand the bonding areas: 20 mm at each strut end, and the skid where it passes through each block.
4. Push a rubber cap on each skid end.

**Check before moving on.** The four struts are the same length within 1 mm.

### 3.9 Arm tubes (four)

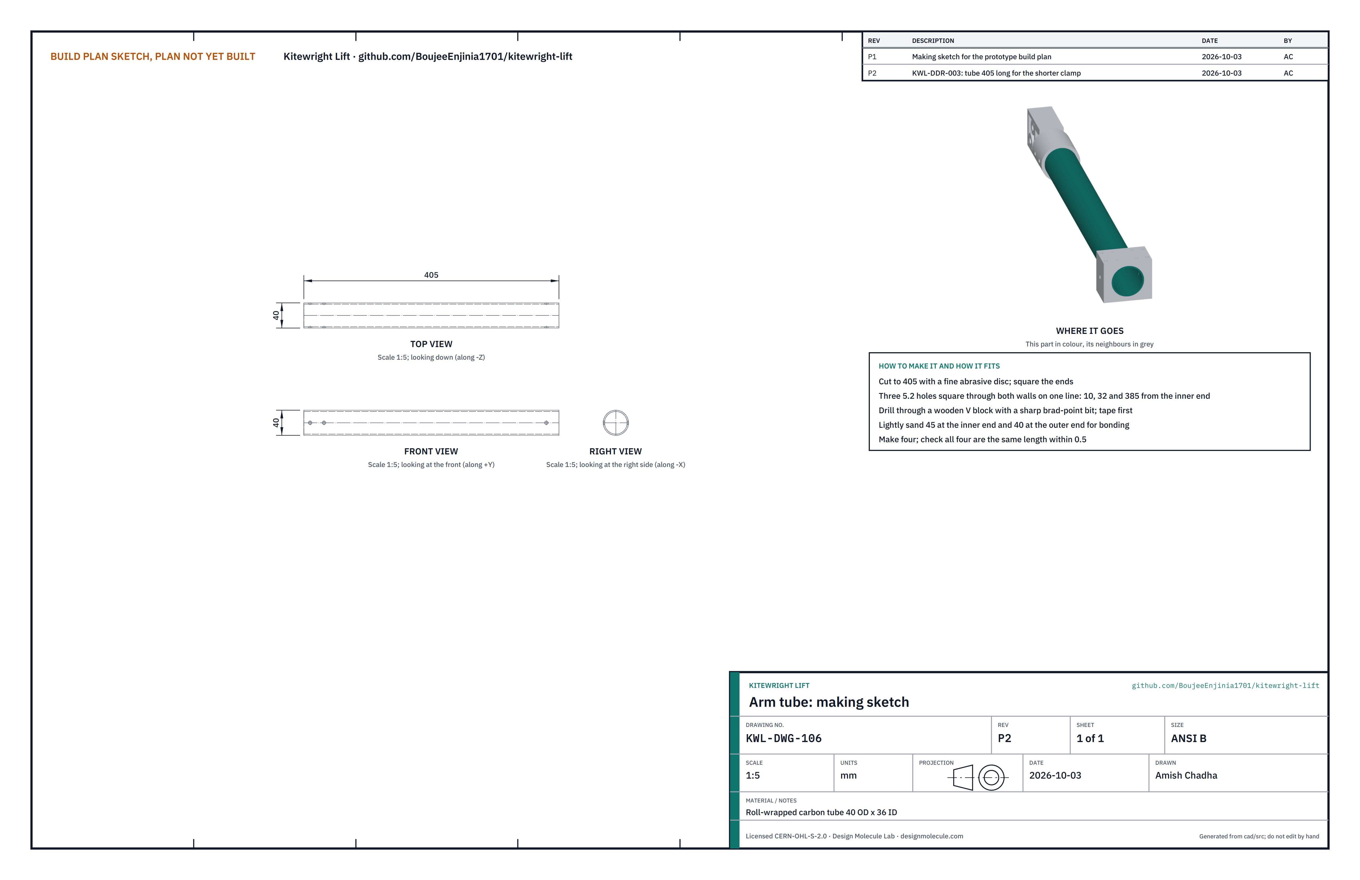
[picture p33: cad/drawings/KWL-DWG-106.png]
Making sketch: arm tube


**What it is and what it is made from.** Roll-wrapped carbon tube 40 mm across, 36 mm inside, 405 mm long.

**How to make it.**

1. Wrap the cut line with tape and cut with a fine abrasive disc; square the ends.
2. In a wooden V block, drill three 5.2 mm holes square through both walls on one line: 10, 32 and 385 mm from the inner end.
3. Sand 45 mm at the inner end and 40 mm at the outer end for bonding.

**Check before moving on.** The four tubes are the same length within 0.5 mm.

### 3.10 Arm root fittings (four)

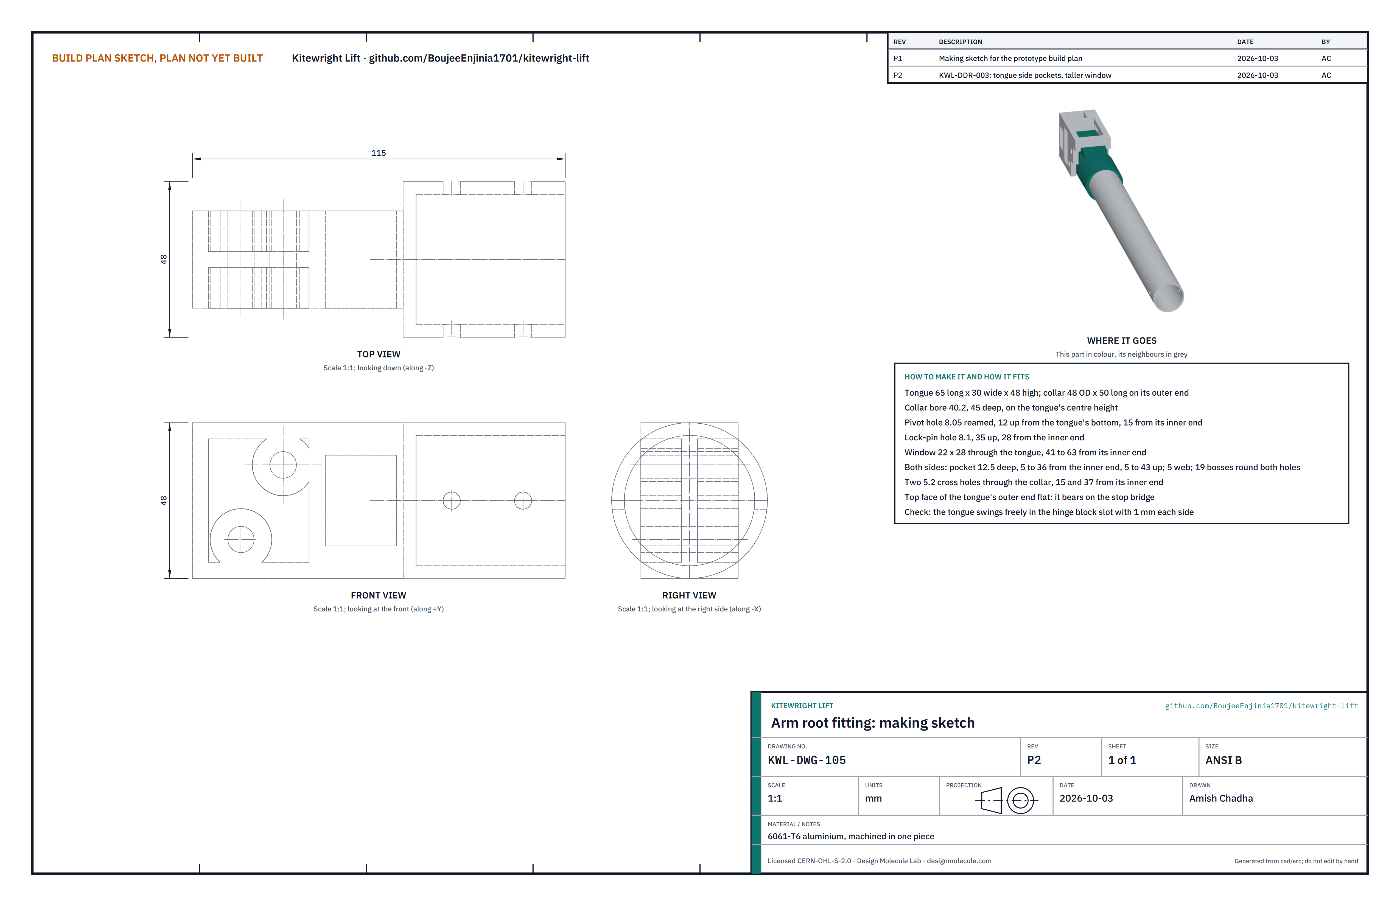
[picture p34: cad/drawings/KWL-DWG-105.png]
Making sketch: arm root fitting


**What it is and what it is made from.** One machined 6061-T6 piece: a 65 x 30 x 48 mm tongue with a 48 mm collar on its outer end.

**How to make it.**

1. Turn the collar to 48 mm and bore it 40.2 mm, 45 mm deep, on the tongue's centre height.
2. Mill the tongue to 30 mm wide and 48 mm high.
3. Ream the pivot hole 8.05 mm, 12 mm up from the tongue's bottom and 15 mm from its inner end; drill the lock-pin hole 8.1 mm, 35 mm up and 28 mm from the inner end.
4. Mill the 22 x 28 mm window through the tongue, 41 to 63 mm from its inner end.
5. Mill a pocket 12.5 mm deep into each side of the tongue, 5 to 36 mm from its inner end and 5 to 43 mm up, leaving a 5 mm web in the middle and a 19 mm round boss of full width round the pivot hole and the lock-pin hole.
6. Drill two 5.2 mm cross holes through the collar, 15 and 37 mm from its inner end.
7. Keep the top face of the tongue's outer end flat: it bears on the bridge.

**How it fits the parts next to it.**

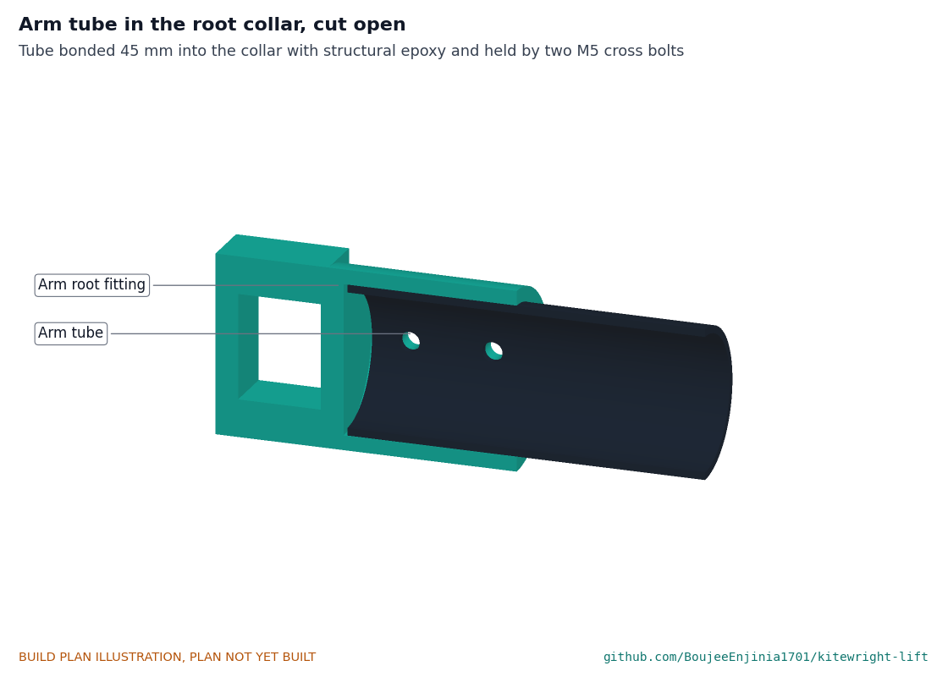
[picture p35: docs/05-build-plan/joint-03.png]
Close-up: arm tube in the root collar, cut open


*Figure 7. The tube goes 45 mm into the collar, bonded with structural epoxy and held by two M5 bolts through collar and tube.*

**Check before moving on.** The tongue swings freely in a hinge block's slot with about 1 mm each side.

### 3.11 Motor mounts (four)

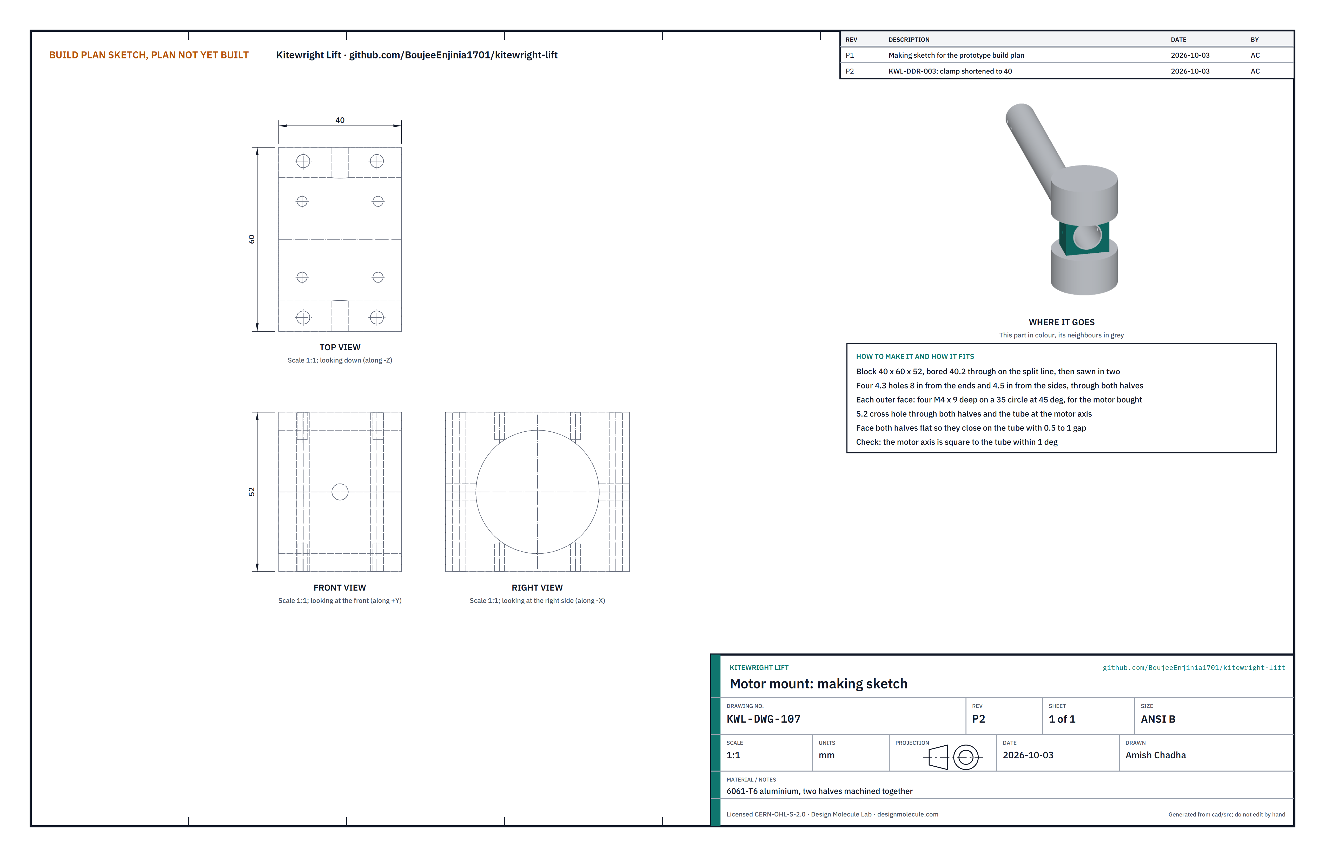
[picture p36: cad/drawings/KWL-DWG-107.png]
Making sketch: motor mount


**What it is and what it is made from.** A split clamp on the arm tip, 40 x 60 x 52 mm (40 mm along the arm), two halves of 6061-T6 machined together.

**How to make it.**

1. Square the block, bore it 40.2 mm on the split line, then saw it in two and face both halves so they close on the tube with a 0.5 to 1 mm gap.
2. Drill four 4.3 mm clamp holes through both halves, 8 mm in from the ends and 4.5 mm in from the sides.
3. Tap four M4 holes 9 mm deep in each outer face to suit the motors bought (a 35 mm circle on most motors of this class).
4. Drill a 5.2 mm cross hole through both halves at the motor axis.

**How it fits the parts next to it.**

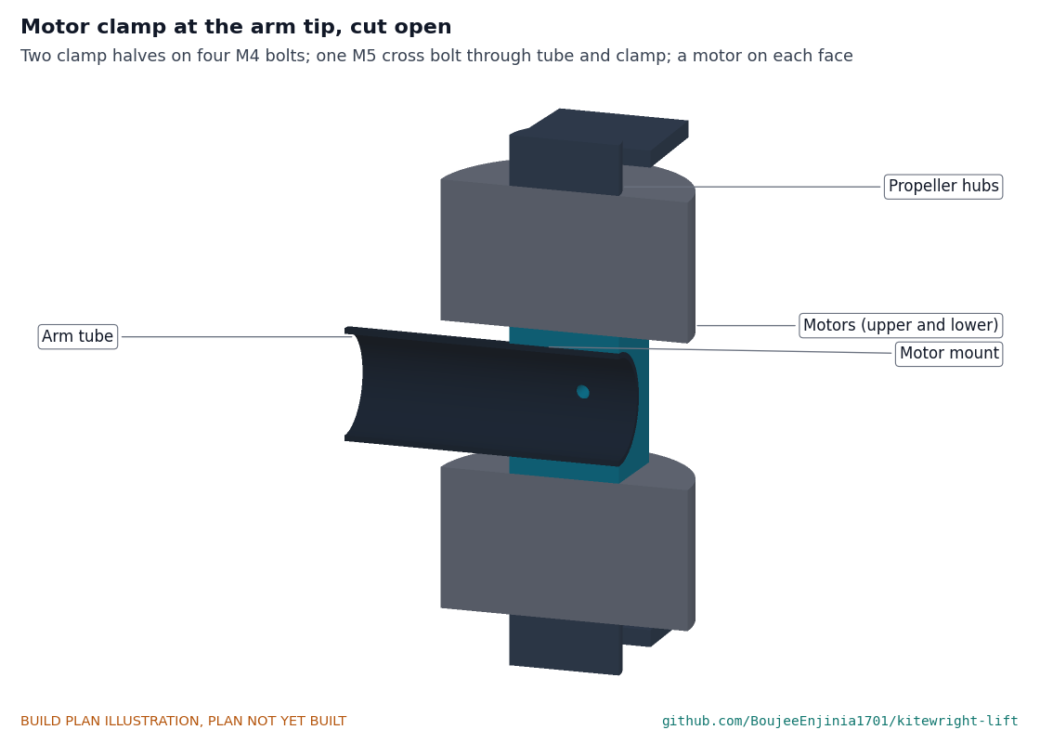
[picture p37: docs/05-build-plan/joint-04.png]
Close-up: motor clamp at the arm tip, cut open


*Figure 8. The clamp halves close on the tube with four M4 bolts and one M5 cross bolt through tube and clamp; the upper motor sits on the top face and the lower motor, upside down, on the bottom face.*

**Check before moving on.** The motor axis is square to the tube within 1 degree.

### 3.12 Motors, controllers and propellers (bought)

Buy eight brushless motors for 30 inch propellers, about 100 KV, rated 12S to 16S, about 450 g, with a maker's figure of about 10 kg static thrust on a 30 x 10 propeller at 51 V; eight controllers rated 16S and 80 A continuous with telemetry; and eight 30 x 10 carbon folding propellers, four turning each way. Upper and lower rotors on each arm turn opposite ways. Balance each propeller before fitting.

### 3.13 Pivot bolts and lock pins (bought)

Buy four stainless M8 shoulder bolts with an 8 mm shoulder 50 mm long, nyloc nuts and washers, and four 8 mm ball-lock pins with a grip of about 55 mm, a ring handle, a lanyard and a red flag. Tie each pin's lanyard to its hinge block so it cannot be lost.

### 3.14 Battery deck

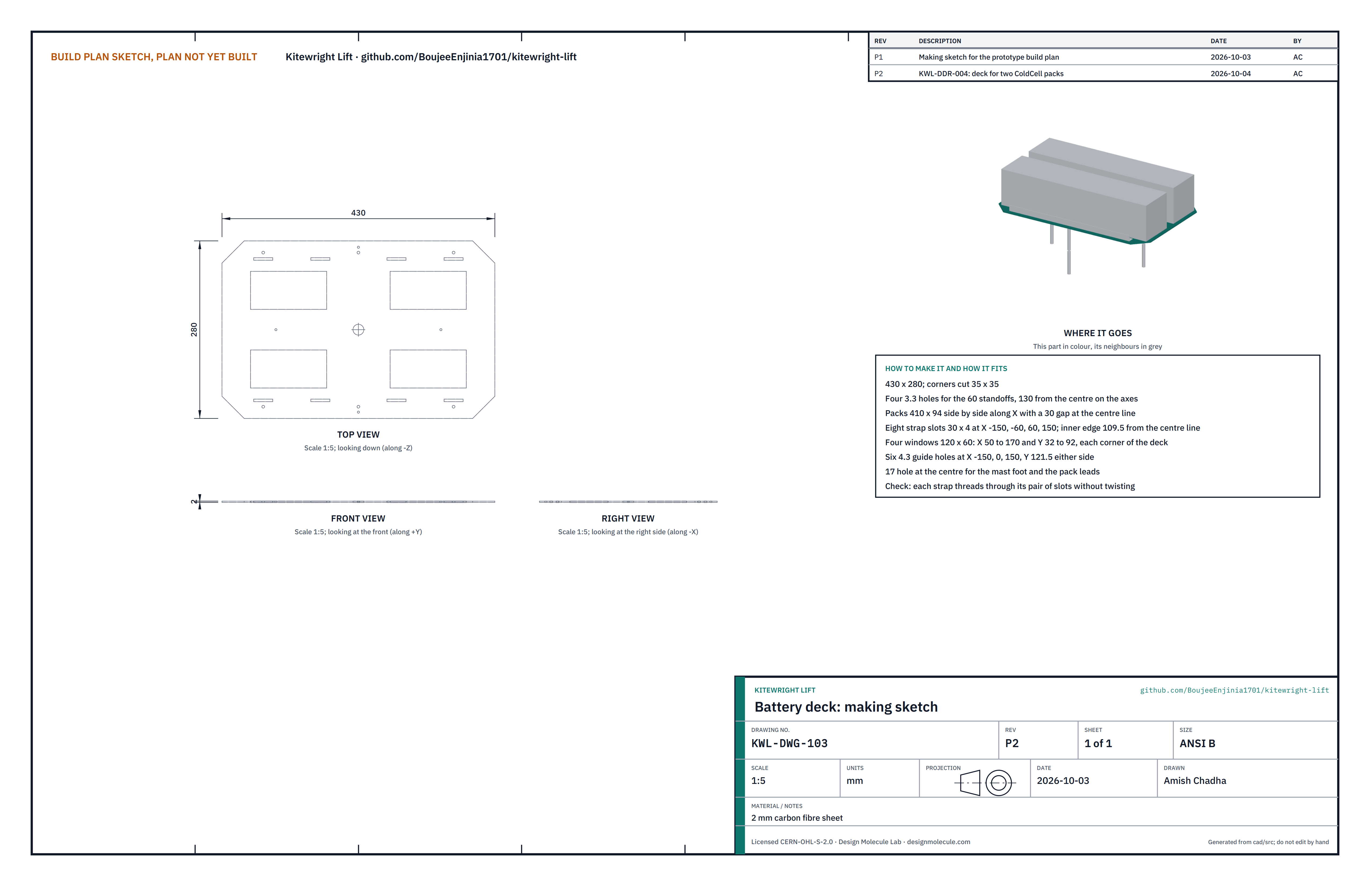
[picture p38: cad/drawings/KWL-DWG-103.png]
Making sketch: battery deck


**What it is and what it is made from.** The shelf the two ColdCell packs sit on: 2 mm carbon sheet, 430 x 280 mm with 35 mm corner cuts, sized for two 410 x 94 x 94 mm packs side by side with a 30 mm gap for the GNSS mast.

**How to make it.**

1. Route the outline.
2. Drill four 3.3 mm standoff holes 130 mm from the centre on the forward, back, left and right lines, and a 17 mm hole at the centre.
3. Cut eight 30 x 4 mm strap slots at 150 and 60 mm ahead of and behind the centre, their inner edges 109.5 mm out on each side.
4. Cut four 120 x 60 mm lightening windows, one under each pack end: 50 to 170 mm ahead of and behind the centre, 32 to 92 mm out on each side.
5. Drill six 4.3 mm guide holes at the centre and 150 mm either side, 121.5 mm out on each side.

**How it fits the parts next to it.**

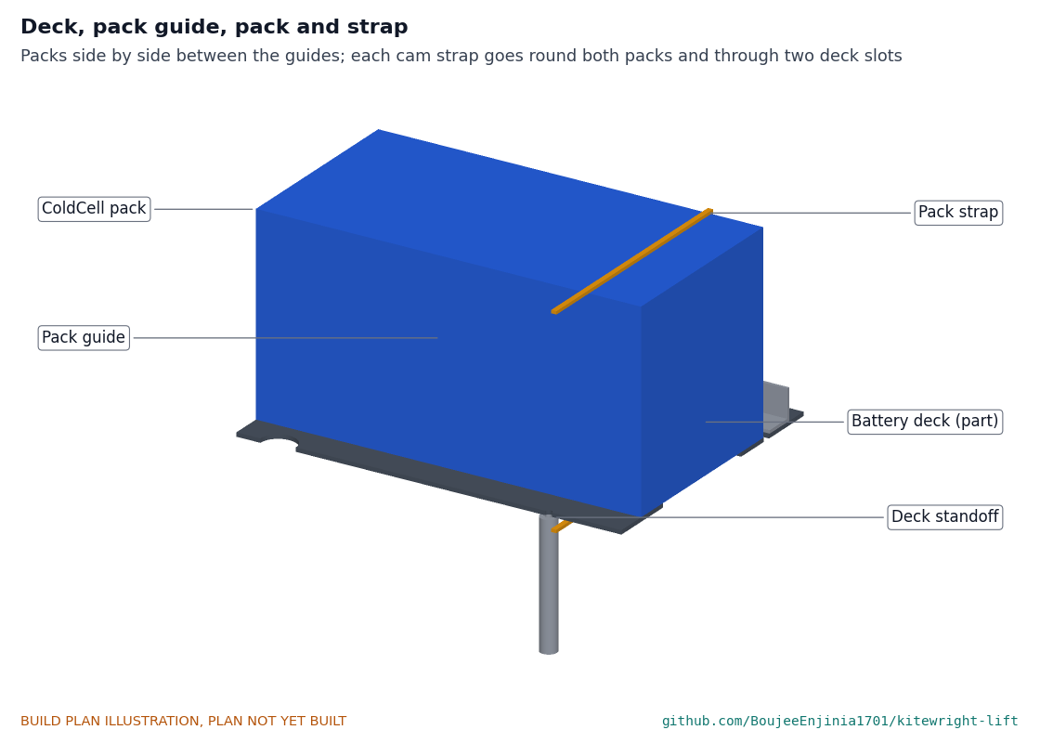
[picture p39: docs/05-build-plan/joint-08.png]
Close-up: deck, pack guide, pack and strap


*Figure 9. The packs sit side by side between the guides; each cam strap goes round both packs and through two deck slots.*

**Check before moving on.** Each strap threads through its pair of slots without twisting.

### 3.15 Pack guides (two)

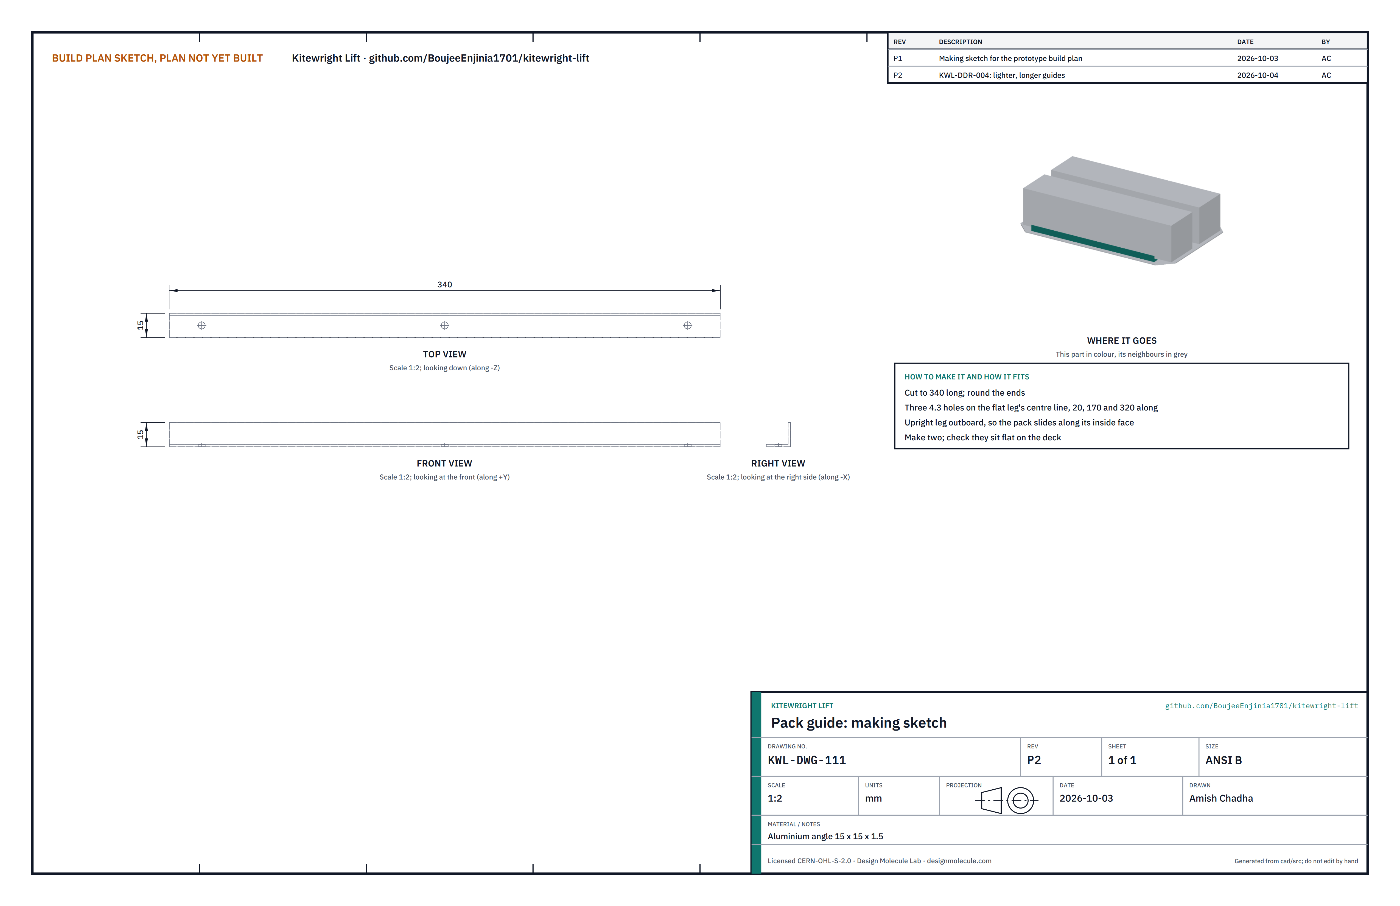
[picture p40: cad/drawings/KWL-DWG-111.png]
Making sketch: pack guide


Cut two pieces of 15 x 15 x 1.5 mm aluminium angle 340 mm long, round the ends, and drill three 4.3 mm holes on the flat leg's centre line, 20, 170 and 320 mm along. Fit with the upright leg outboard. Check they sit flat on the deck.

### 3.16 Pack straps and GNSS mast (bought)

Buy four 25 mm cam-buckle straps 900 mm long with rubber backing (each goes round both packs), and a 16 mm carbon GNSS mast 230 mm long with a foot clamp; the Core's GNSS receiver goes on top of it.

### 3.17 ColdCell packs (built to the ColdCell design)

Build two lithium-ion ColdCell packs to the ColdCell build plan's variant for Lift: 14 cells in series and three in parallel, 21700 high-power lithium-ion cells of about 4.5 Ah rated for 45 A, with the external film heater, insulation, BMS and shell. Each pack is 50.4 V nominal (42.0 to 58.8 V), 680 Wh, 410 x 94 x 94 mm and 4.46 kg, with an AS150 power lead, exactly as ColdCell draws it (CCL-DWG-002).

**Operating note: warm weather.** ColdCell keeps its 50 °C firmware warning for this pack until a TRL 4 measurement supports relaxing it. A full hover flight stays under the warning up to about 27 °C ambient. Above that, plan shorter flights: at 45 °C the warning comes after about 6 min of hover. Land when it comes.

> **Safety:** Lithium-ion cells hold more fire energy than the LiFePO4 cells first planned. Keep every ColdCell protection: the BMS blocks charging below 5 °C, the heater has cut-outs, every cell has its own fuse, the 50 °C warning lands the aircraft, and packs are charged only inside the fire-resistant charging box.

### 3.17a Power leads from the frame to the Core (bought, made up)

Lift supplies the power leads between its packs and the Core, and between the Core and its arms, because the Core no longer carries them. Make them from 8 AWG silicone wire, red and black, with four AS150 anti-spark connector halves: two for the pack inputs and two for the frame outputs. Solder the leads to the Core's pads, clamp them under its strain-relief bar and lead them out through the lid's grommets, keeping each lead as short as the route allows. Insulate every joint with heat-shrink before a pack is anywhere near.

### 3.18 Payload shoes (two)

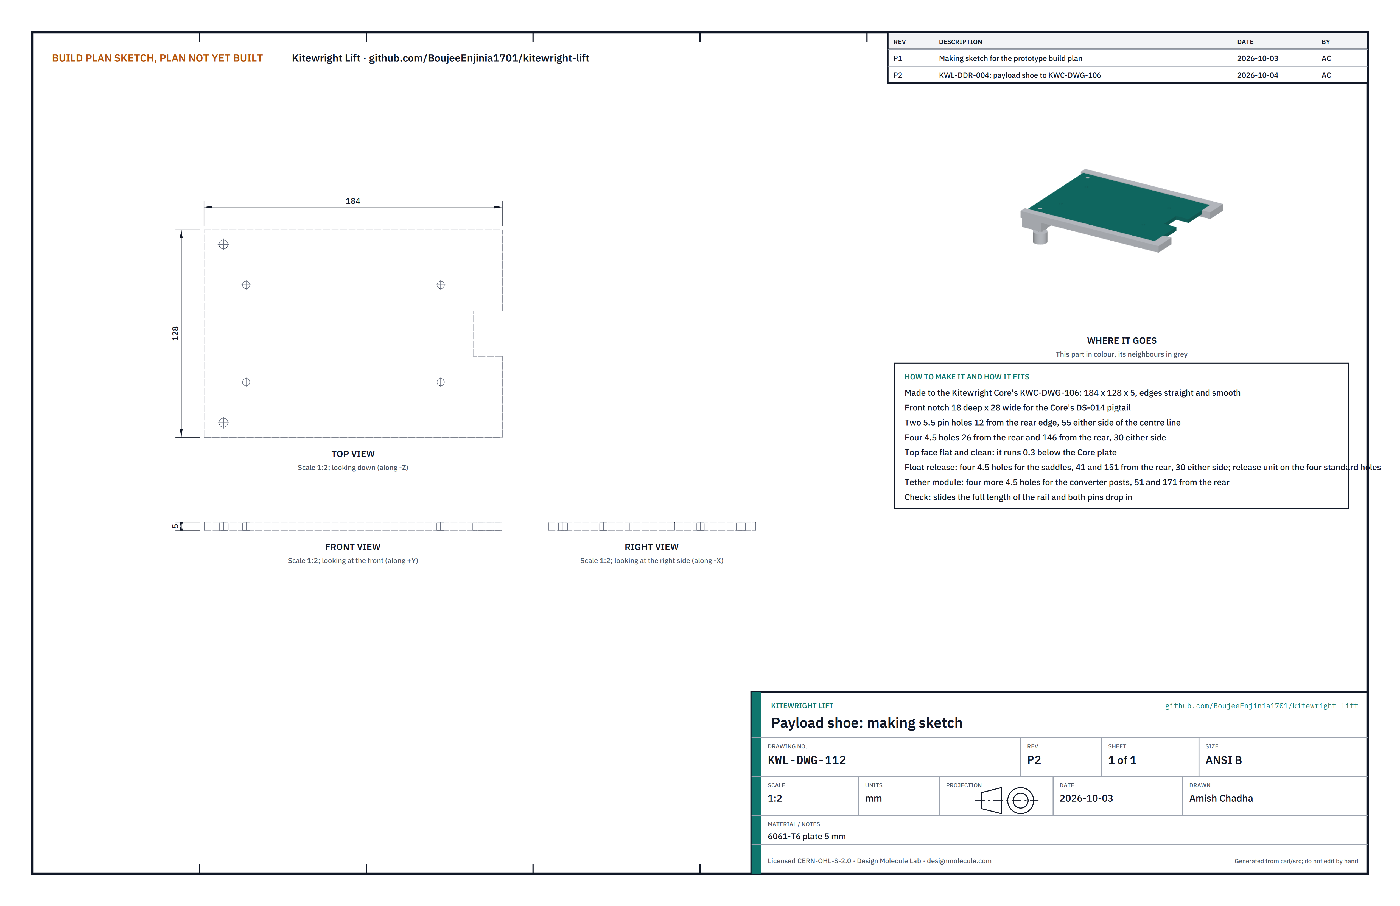
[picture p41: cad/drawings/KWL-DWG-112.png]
Making sketch: payload shoe


**What it is and what it is made from.** The shoe every Kitewright payload is built on, made to the Core's drawing KWC-DWG-106: 6061-T6 plate, 184 x 128 x 5 mm.

**How to make it.**

1. Cut the plate square with straight, smooth long edges: they ride on the Core rail's lips.
2. Cut the 18 x 28 mm notch in the front edge for the Core's DS-014 pigtail.
3. Drill the two 5.5 mm locking pin holes 12 mm from the rear edge, 55 mm either side of the centre line, and the four 4.5 mm holes 26 and 146 mm from the rear, 30 mm either side.
4. Float release shoe: four more 4.5 mm holes for the saddles, 41 and 151 mm from the rear, 30 mm either side. Tether module shoe: four more 4.5 mm holes for the converter posts, 51 and 171 mm from the rear, 30 mm either side.

**How it fits the parts next to it.** Everything a payload hangs from the shoe stays inside 88 mm wide from the shoe down to 30 mm below the rail lips (the payload neck), clear of the Core's pin knobs at the back and its pigtail plug at the front.

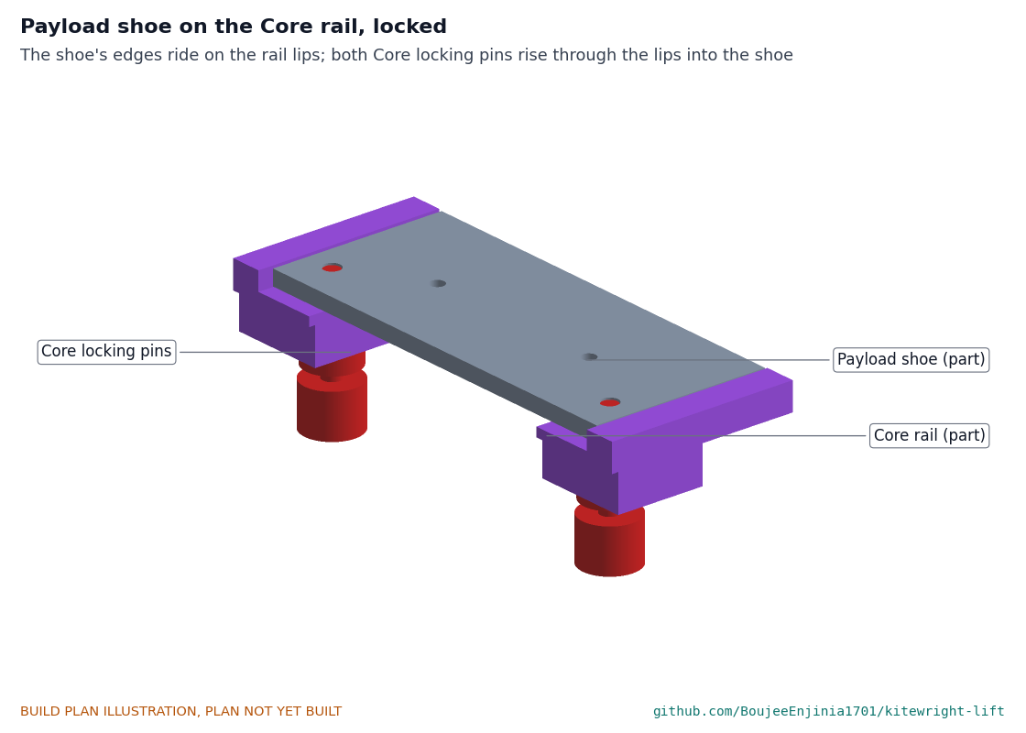
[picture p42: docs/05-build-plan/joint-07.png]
Close-up: payload shoe on the Core rail, locked


*Figure 10. The shoe's edges ride on the rail lips under the Core plate; both locking pins rise through the lips into the shoe.*

**Check before moving on.** The shoe slides the full length of the rail to the front stops and both pins drop in.

### 3.19 Float saddles (two)

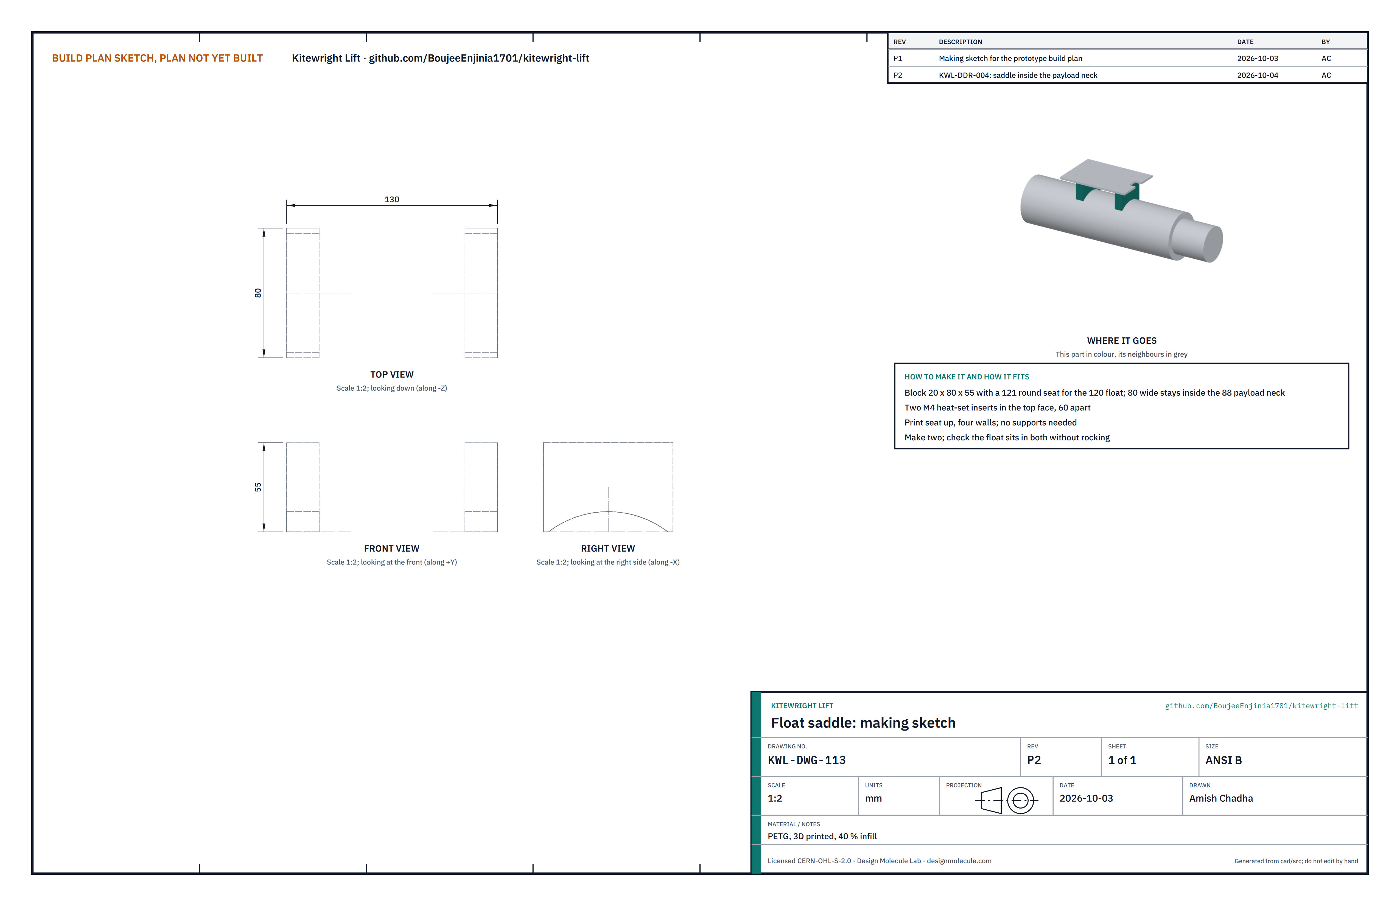
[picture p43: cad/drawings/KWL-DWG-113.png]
Making sketch: float saddle


Print two saddles in PETG, 20 x 80 x 55 mm with a 121 mm round seat, seat up, four walls and 40 % infill; set two M4 heat-set inserts in each top face 60 mm apart. At 80 mm wide they stay inside the payload neck, and at 55 mm tall the float hangs below it. Check the float sits in both without rocking.

### 3.20 Float sling

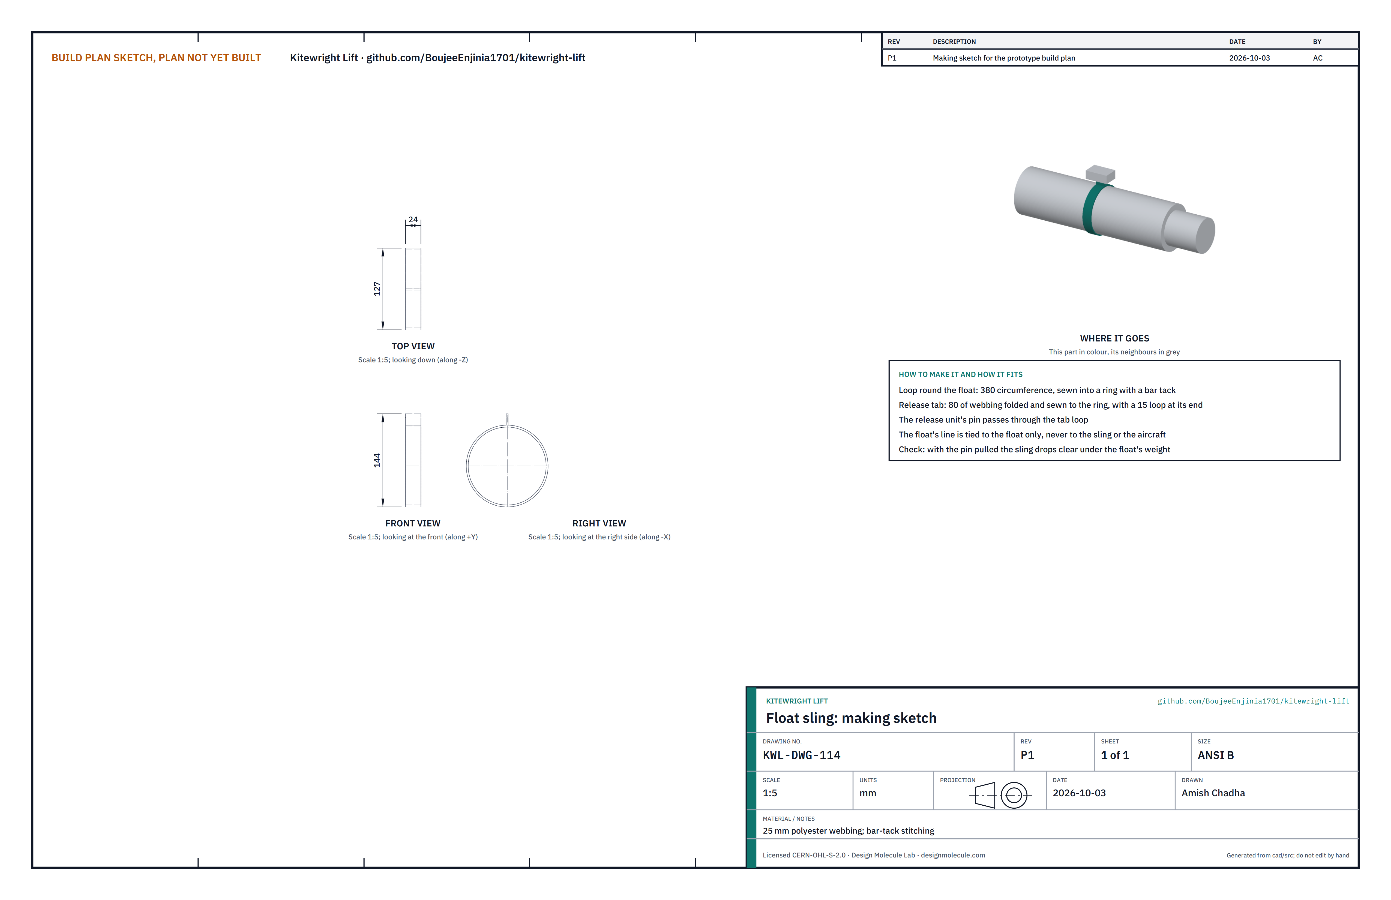
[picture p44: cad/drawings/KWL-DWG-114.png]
Making sketch: float sling


Sew a ring of 25 mm polyester webbing 380 mm round to fit the float, with a bar tack. Sew an 80 mm tab to it with a 15 mm loop at its end for the release pin. The float's line is tied to the float only, never to the sling or the aircraft. Check that with the pin pulled the sling drops clear under the float's weight.

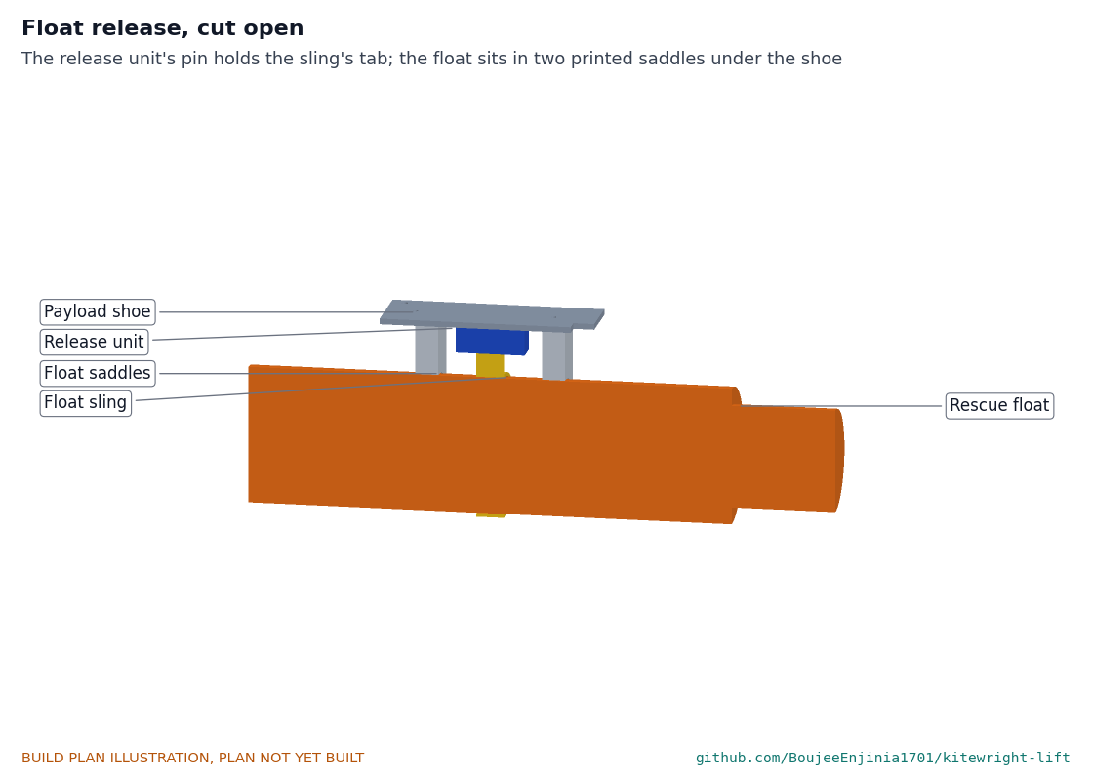
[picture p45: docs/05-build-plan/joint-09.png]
Close-up: float release, cut open


*Figure 11. The release unit's pin holds the sling's tab; the float sits in the two saddles.*

### 3.21 Release unit, float and line (bought)

Buy a servo-driven pin release rated 10 kg that stays closed when unpowered, a closed-cell foam rescue float about 120 x 420 mm (about 0.6 kg), and 30 m of 6 mm floating line in a throw bag that clips to the float's end.

### 3.22 Tether module and ground set (bought)

Buy an isolated DC-DC converter (380 to 420 V in, 51 V out, 4 kW, conduction cooled, about 200 x 110 x 65 mm), a two-pole 600 V breakaway connector that pulls apart at about 200 N, 60 m of tether with two 0.75 mm2 conductors and an aramid strength member, a 400 V DC isolated ground supply of 4.5 kW, a hand reel with a 600 V slip ring, and a ground safety set: insulation monitor, emergency stop, residual-current protection and an earth spike.

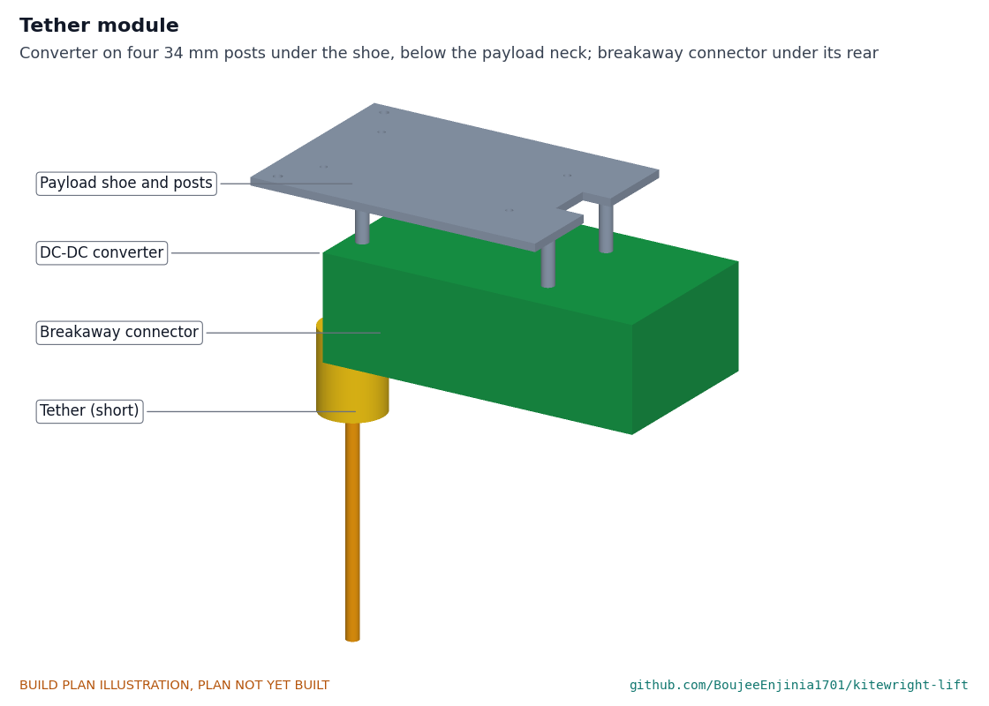
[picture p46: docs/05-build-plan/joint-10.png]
Close-up: tether module


*Figure 12. The converter on four 34 mm posts under the shoe, below the payload neck and 20 mm ahead of the Core's pin knobs; the breakaway connector under its rear end.*

## 4. Putting it together

Use medium threadlocker on every metal-to-metal screw. Bonded joints use structural epoxy on sanded, cleaned surfaces and cure for 24 h before load.

### Step 1: Bolt the hinge blocks to the bottom plate

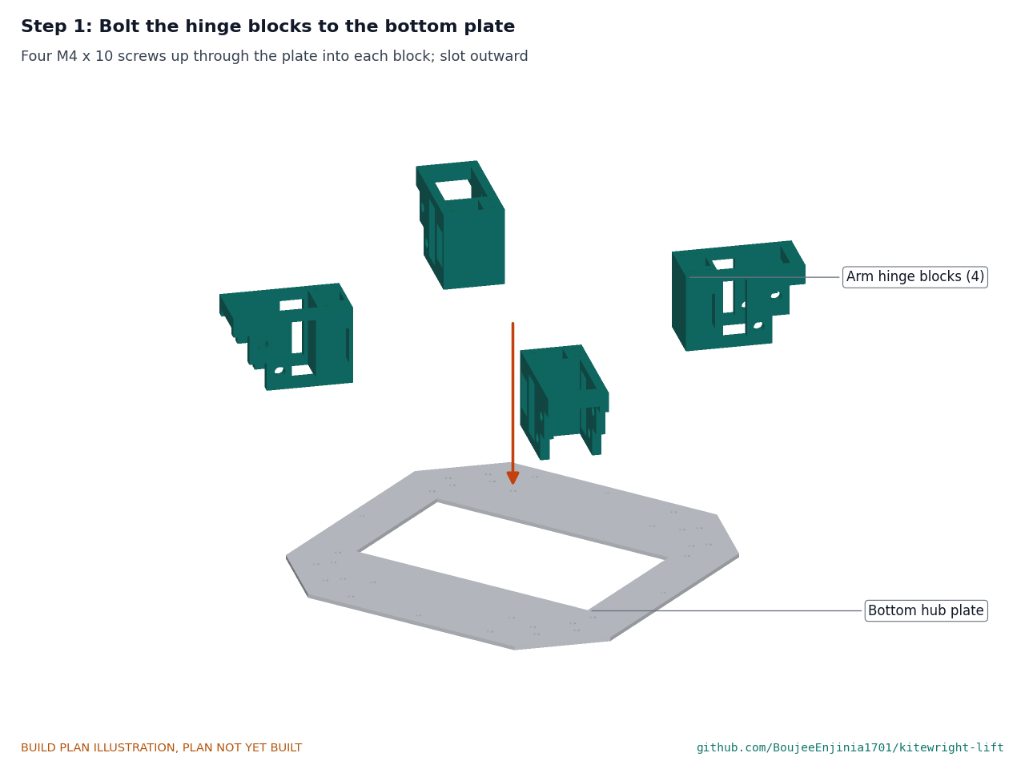
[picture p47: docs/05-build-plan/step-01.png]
Step 1


Four M4 x 10 screws up through the plate into each block, slot facing out along the diagonal.

### Step 2: Fit the hub spacers

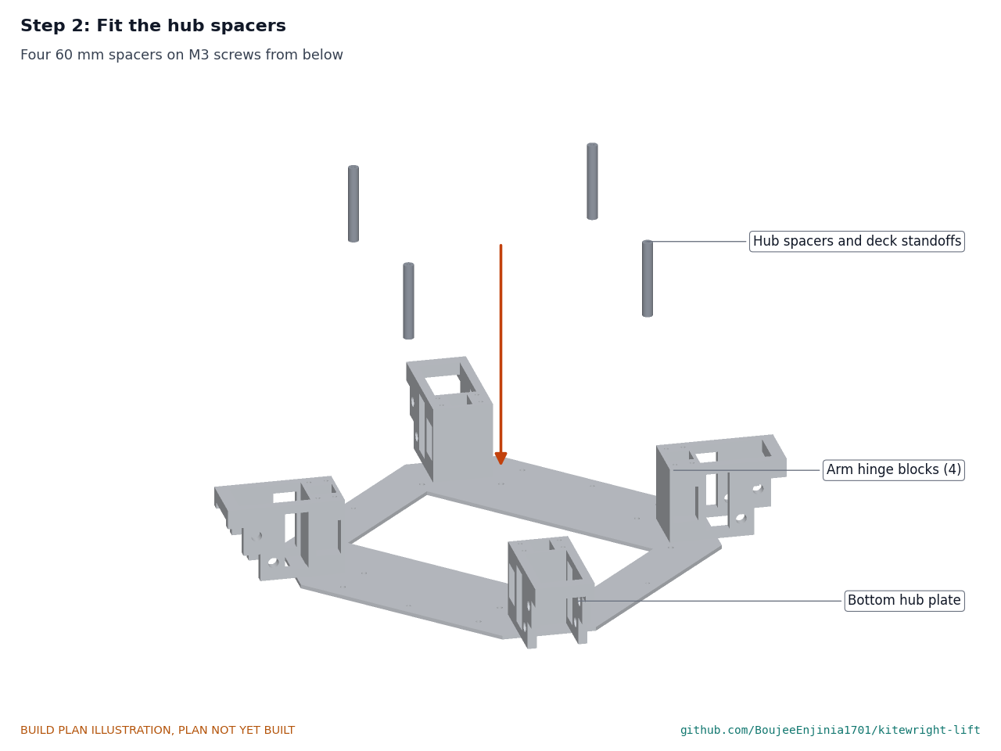
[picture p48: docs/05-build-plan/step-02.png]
Step 2


The four 60 mm spacers on M3 screws from below.

### Step 3: Fit the top hub plate

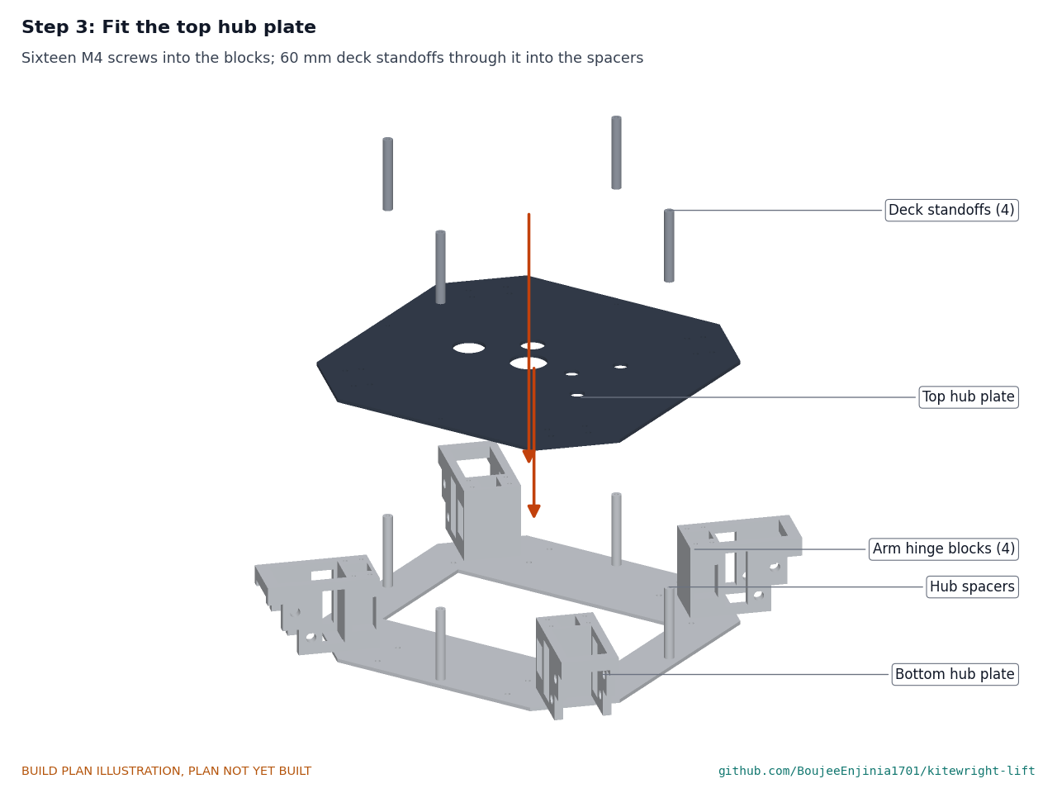
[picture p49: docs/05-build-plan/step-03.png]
Step 3


Sixteen M4 screws down into the hinge blocks; the four 60 mm deck standoffs screwed through the plate into the spacers.

### Step 4: Build the landing gear

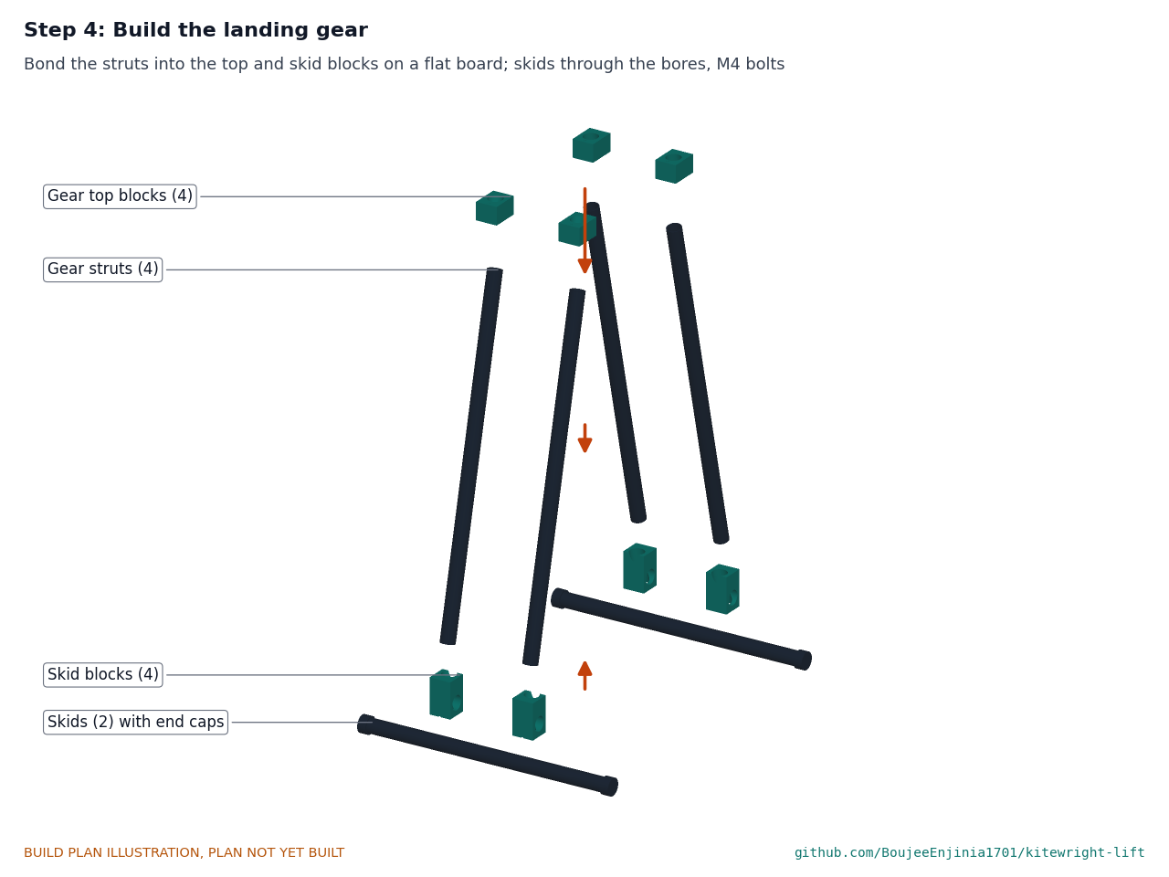
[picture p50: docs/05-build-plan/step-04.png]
Step 4


On a flat board, bond the struts into the top and skid blocks with the skids through their bores, and bolt each skid with its M4 bolt. Cure 24 h.

### Step 5: Bolt the gear under the hub

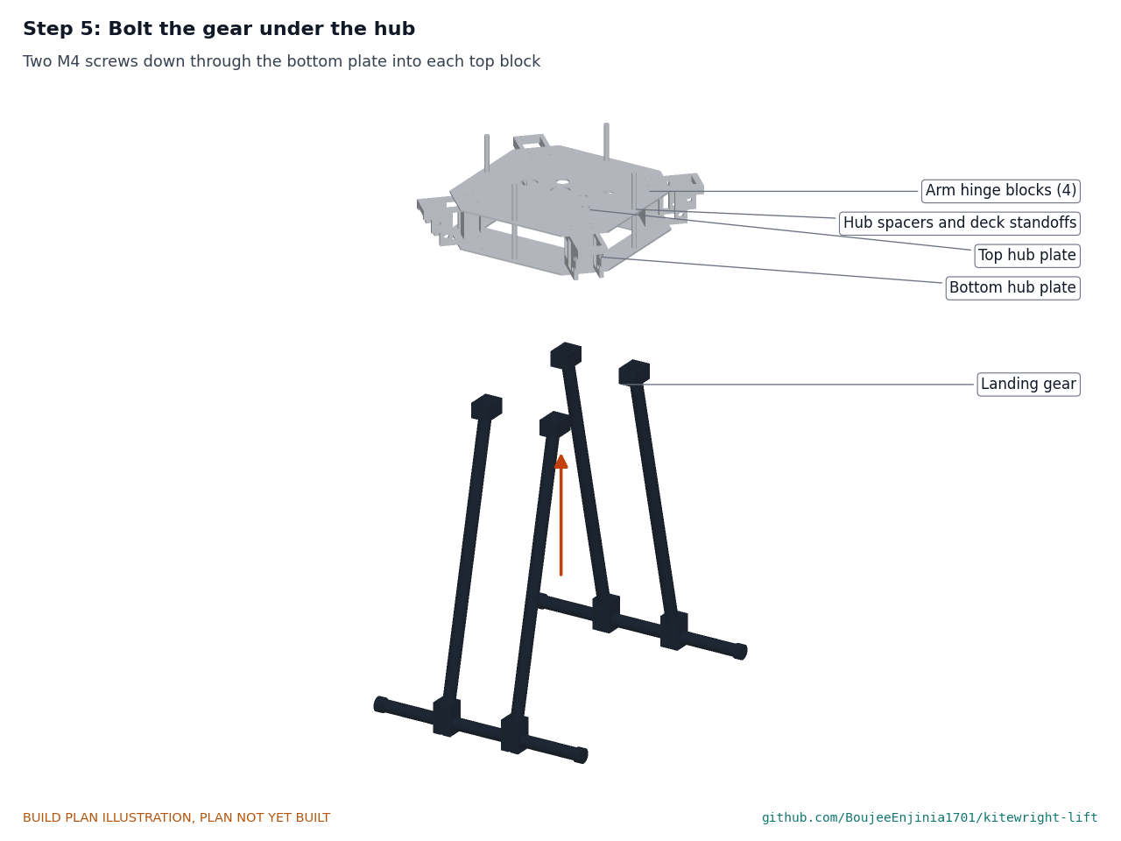
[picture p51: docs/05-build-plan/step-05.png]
Step 5


Two M4 screws down through the bottom plate into each top block.

### Step 6: Hang the Kitewright Core under the hub

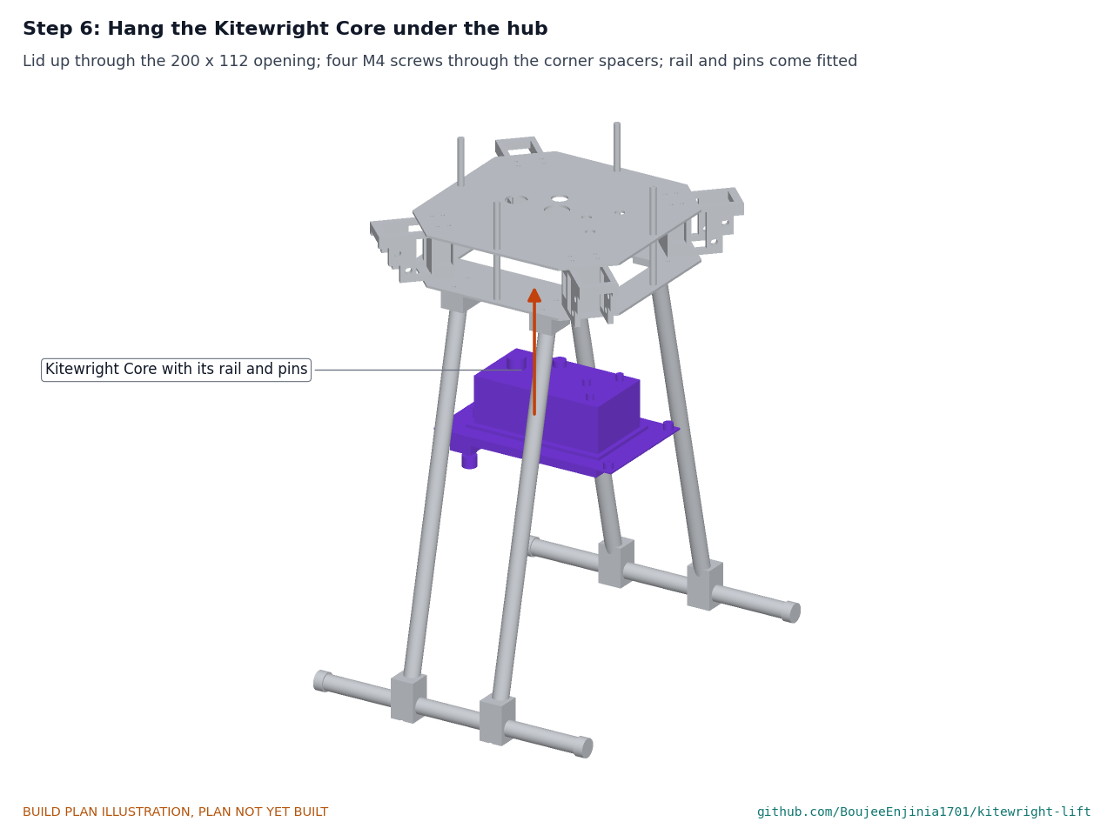
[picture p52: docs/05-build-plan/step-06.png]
Step 6


From below, push the Core's lid up through the 200 x 112 mm opening until its four corner spacers meet the bottom plate; four M4 screws down through the plate into them. The rail, locking pins and pigtail come fitted. Check that the mast boss, SMA bulkheads and switch sit in their holes in the top plate without touching. Route the eight controller leads to the Core.

### Step 7: Make up each arm

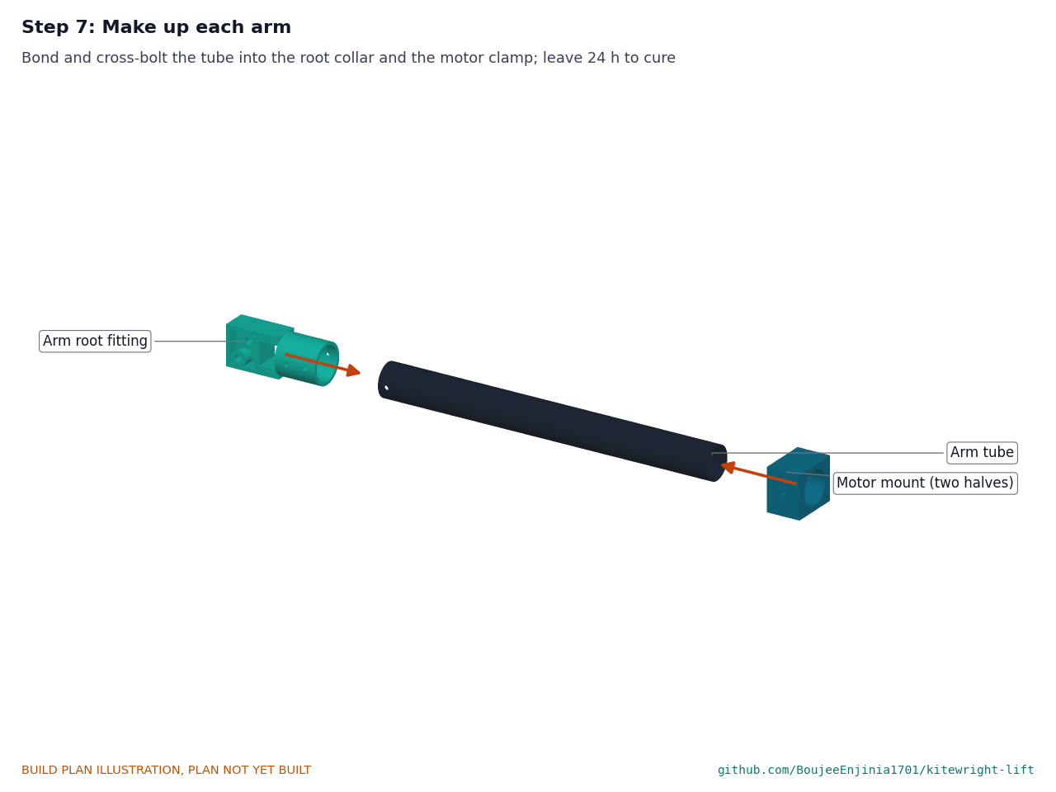
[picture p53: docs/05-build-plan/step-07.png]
Step 7


Bond the tube 45 mm into the root fitting's collar and 40 mm into the motor clamp, with the clamp's top face square to the tongue's top. Fit the two M5 bolts through collar and tube and the M5 bolt through clamp and tube; close the clamp's four M4 bolts. Cure 24 h. Make four.

### Step 8: Fit the motors and controllers

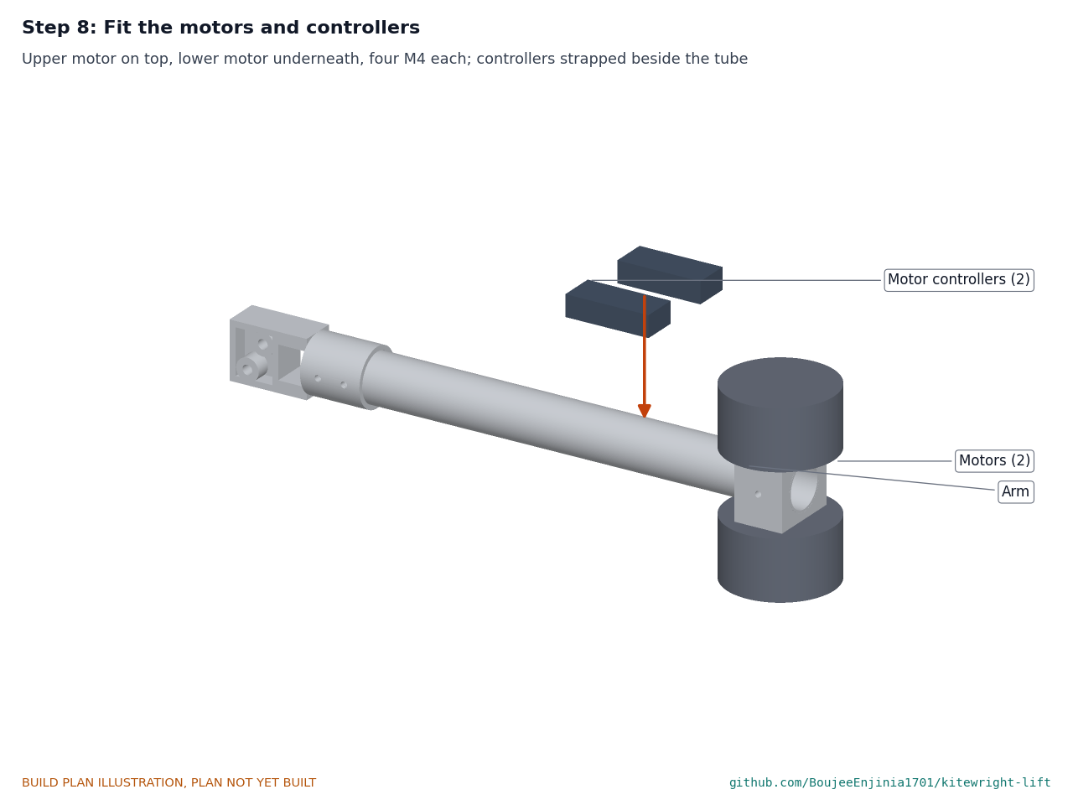
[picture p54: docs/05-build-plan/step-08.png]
Step 8


Upper motor on the clamp's top face and lower motor, upside down, on its bottom face, four M4 screws each. Strap a controller to each side of the tube near the tip and solder or plug the motor leads. Leave a 60 mm slack loop in the two power leads where they will cross the hinge.

### Step 9: Hang each arm in its hinge block

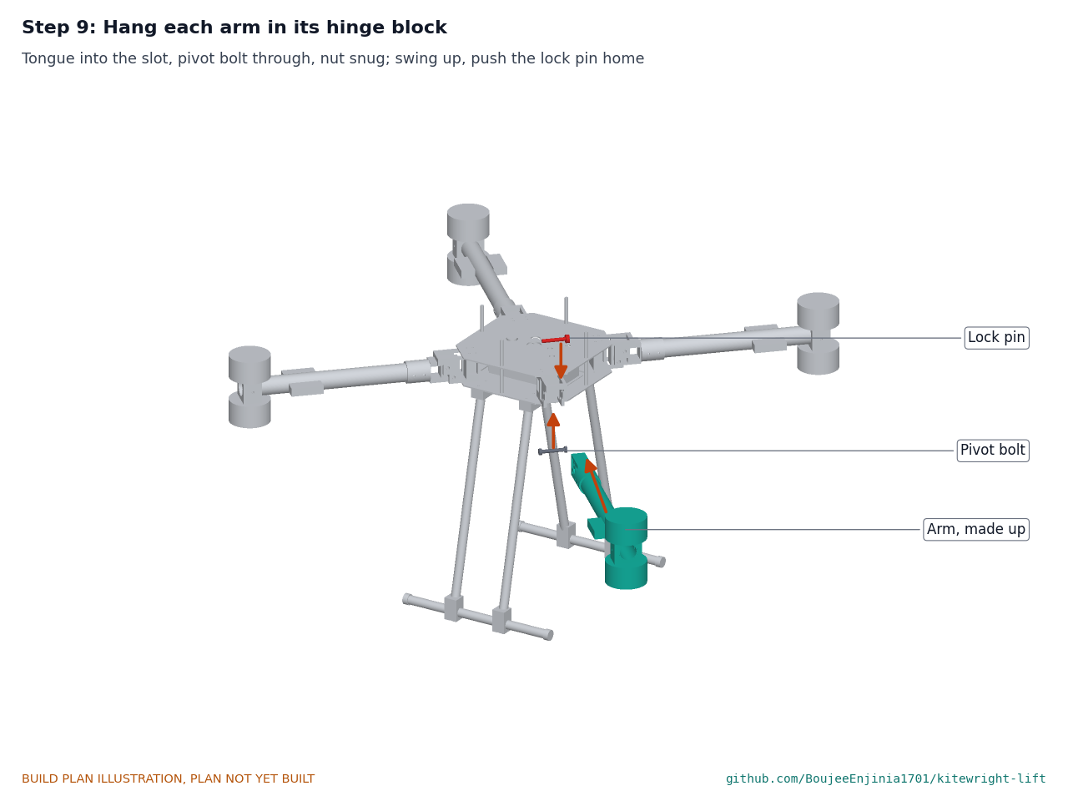
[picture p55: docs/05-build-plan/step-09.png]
Step 9


Slide the tongue into the slot, push the pivot bolt through block and tongue, and snug the nyloc nut so the arm swings without play. Swing the arm up until its tongue meets the stop bridge and push the lock pin home. **Hold point:** each hinge is proof-loaded before first flight (section 6).

### Step 10: Fit the propellers

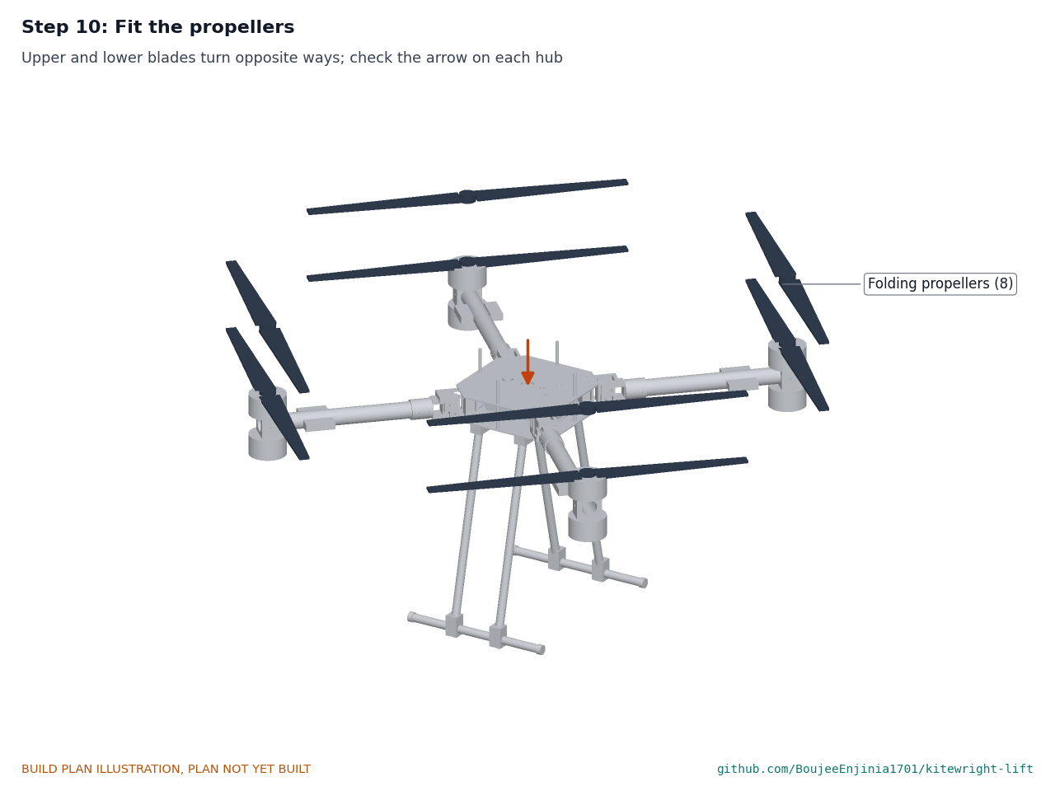
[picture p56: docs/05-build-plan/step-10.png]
Step 10


Check the direction arrow on each hub against the motor's direction: upper and lower rotors on an arm turn opposite ways. **Hold point:** propellers stay off until the first power-up in section 5 is complete.

### Step 11: Fit the battery deck and pack guides

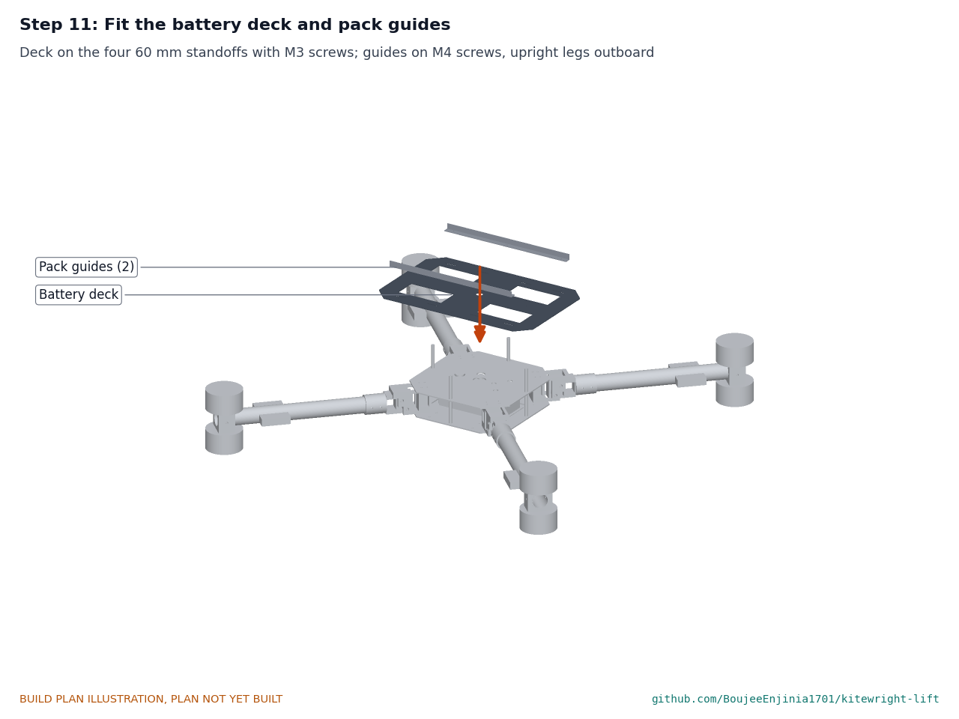
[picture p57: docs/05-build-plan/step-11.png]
Step 11


Deck on the four 60 mm standoffs with M3 screws; guides on M4 screws, upright legs outboard; thread the four straps through their slots.

### Step 12: Fit the GNSS mast and antenna leads

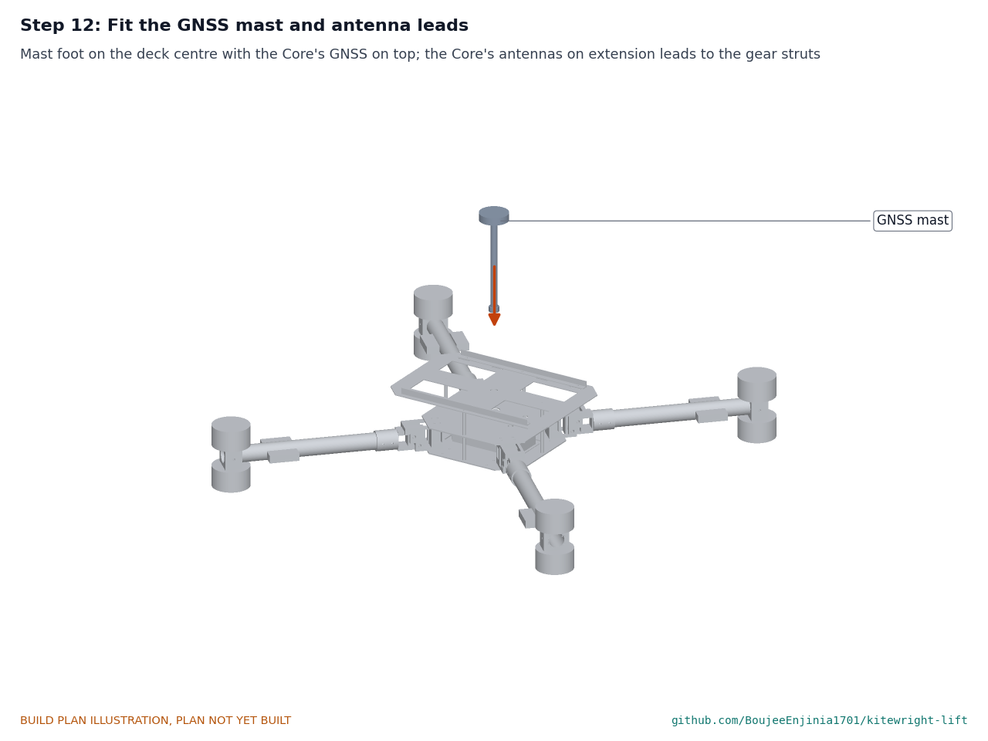
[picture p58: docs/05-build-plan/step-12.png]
Step 12


Mast foot on the deck centre with the Core's GNSS receiver on top; lead its cable down through the deck and top plate to the Core. Screw the three SMA extension leads onto the Core's bulkheads through the top plate holes and clip the antennas to the rear gear struts, pointing down.

### Step 13: Fit the ColdCell packs

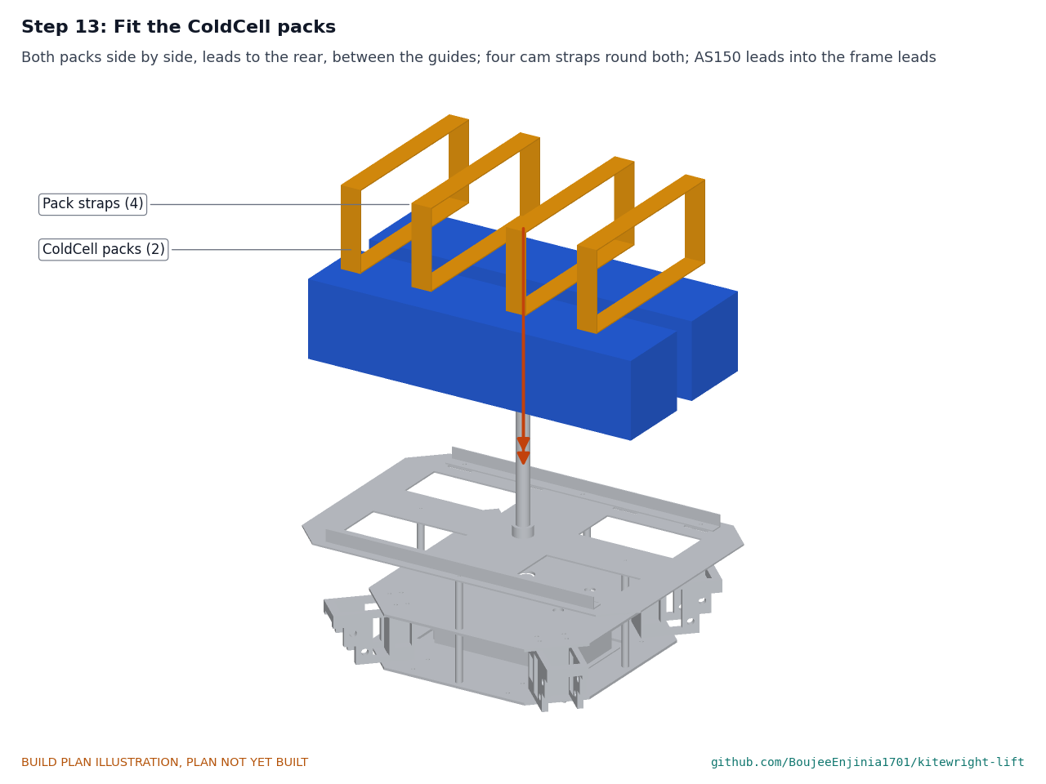
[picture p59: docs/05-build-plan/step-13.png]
Step 13


Lay both packs side by side on the deck, leads to the rear, between the guides and either side of the mast; close the four straps round both; plug each into its AS150 lead from the Core. **Hold point:** packs go on only after the safety stop for first power (section 6).

### Step 14: Slide in the float release payload

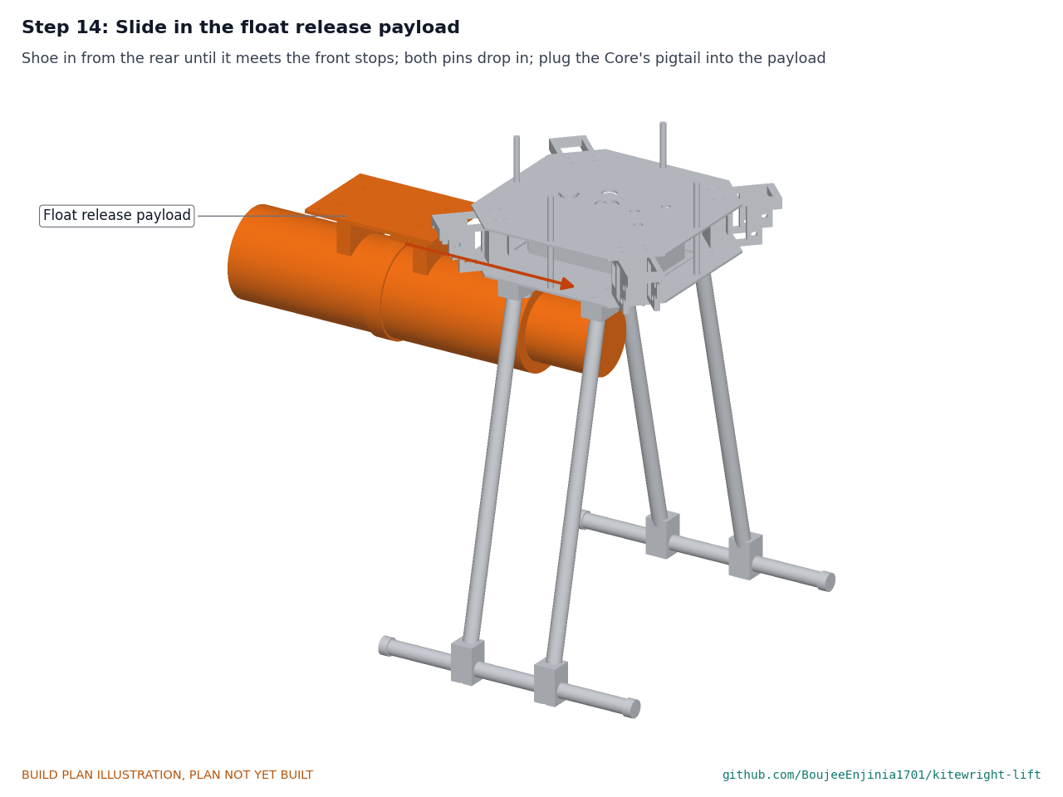
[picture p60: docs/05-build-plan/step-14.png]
Step 14


From the rear, slide the payload shoe onto the rail lips until it meets the front stops; both locking pins drop into its holes (check both red bands are hidden). Plug the Core's DS-014 pigtail into the payload's socket in front of the shoe's notch.

### Step 15: Or slide in the tether module

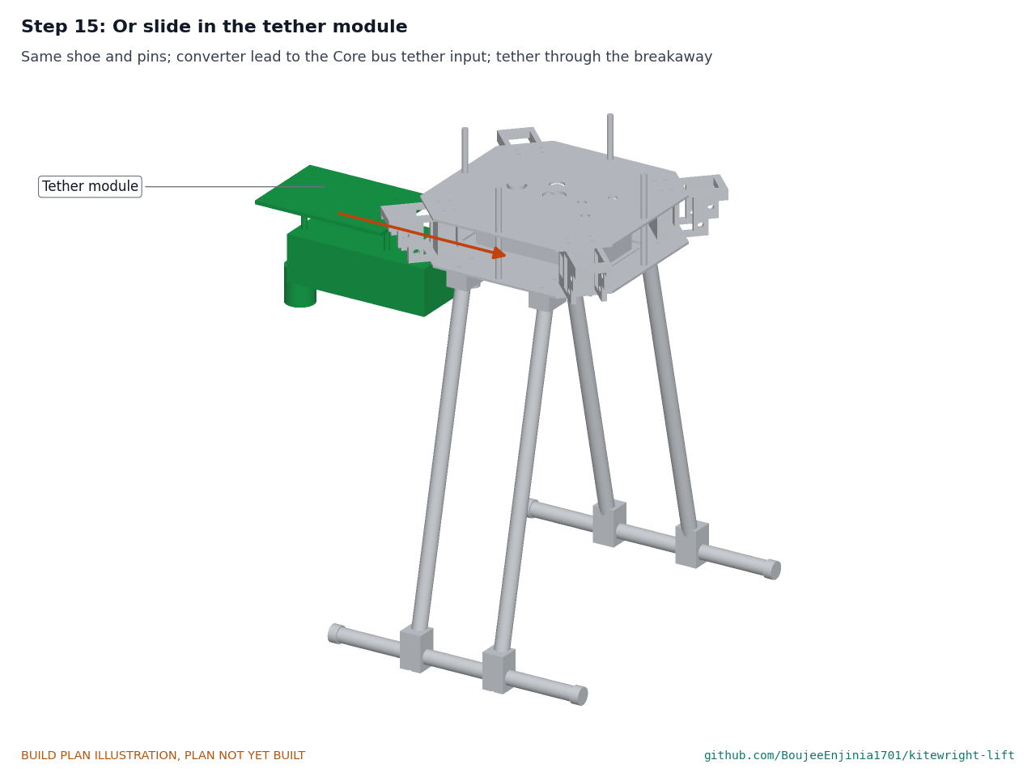
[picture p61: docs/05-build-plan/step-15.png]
Step 15


The same rail and pins. Plug the converter's output lead into the Core bus tether input and lead the tether through the breakaway connector.

### Step 16: Fold for transport

Step 16

Take the payload off. For each arm, pull the lock pin, swing the arm down 90 degrees about its pivot, and turn both blades of each propeller back along the arm. Unfold in reverse; every lock pin goes back in and flagged before arming.

## 5. First checks

| Check | Requirement | How | Pass when |
| --- | --- | --- | --- |
| Weigh ready to fly, then with each payload | R1, R2 | Hanging scale | 25 kg or less with each payload; the rated payload confirmed (3.2 kg on paper) |
| Fold and pack | R9 | Fold, place in a 1.2 x 0.6 x 0.5 m case, unfold and time the set-up | Fits the case; set-up in 10 min or less |
| Hinge proof load | R5 (safety) | Each arm on CalRig at 117 N m (1.5 times full thrust) for 1 min | No movement at the stop, no crack, no yield |
| First power-up, propellers off | R10 | Core on the bench supply, then the packs; every motor turns the right way at low throttle | Each motor turns the right way; no fault on any controller |
| Motor and propeller thrust | R3 | AltiRig at sea-level and 5,000 m density | Full-throttle thrust per motor about 10 kg at sea level |
| Tethered hover on the ground set | R7 | Ground supply, insulation monitor, tether at 10 m height first | Bus steady at 51 V; no insulation alarm |
| Motor-cut test | R5 | One motor cut by the autopilot at 10 m over cleared ground | Controlled descent and landing |
| Hover time | R4 | Timed hover with the rated payload, logged energy and pack temperature | Time recorded against R4 |
| Float drop | R8 | Ten drops from 10 m onto a marked target on water | Float lands within the R8 distance |
| Wind hold | R6 | Logged position hold on a windy day | Position held within the R6 distance |

## 6. Safety stops

1. **Before any machining or cutting of carbon.** Dust extraction or a wet cut and a dust mask; carbon dust is an irritant and conducts electricity, so keep it away from the electronics.
2. **Before the first power-up.** Propellers off. The Core is powered from a current-limited bench supply first. Packs are charged and handled to ColdCell's rules for lithium-ion packs: charging is blocked below 5 °C, packs are charged only in the fire-resistant charging box on a non-flammable surface, with a lithium-rated extinguisher or sand to hand. The frame-to-Core leads are checked for polarity and insulation before the first pack is plugged in.
3. **Before the first flight.** Every hinge proof-loaded on CalRig (section 5) and inspected; every lock pin in and flagged; propellers balanced and checked for cracks; failsafes for loss of link and low battery set and tested; nobody within 15 m; a written arming and keep-out procedure followed.
4. **Before energising the tether.** Ground supply earthed, insulation monitor and residual-current protection working, emergency stop tested, the tether laid clear of people, roads, water currents and power lines, and the breakaway fitted at the aircraft. Nobody touches the tether or the module while the supply is on. First tethered hovers at 10 m; never above 50 m.
5. **Before any payload drop.** Nobody under the aircraft except the person the float is for, who is approached from at least 10 m up; the float's line is tied to the float only. The release is tested on the ground first, with the aircraft unpowered.
6. **Before the motor-cut test.** Done over cleared ground at 10 m with a pilot ready to take over, and only after every other first check passes.
7. **After any hard landing.** Packs removed and watched outside for 24 h; hinges, bridges, pivots and arm tubes inspected before the next flight.

## 7. Tools, skills and workspace

- **Tools:** drill press and a wooden V block; hand drill; fine abrasive cut-off disc or a tube cutter for carbon; files and deburring tool; M3, M4, M5 and M8 hex keys and nut drivers; torque screwdriver; 3D printer (or a printing service); sewing machine for webbing (or a sail or upholstery shop); soldering station for the motor leads; hanging scale to 50 kg; multimeter; insulation tester for the tether set.
- **Bought machining:** the hinge blocks, root fittings, motor clamps and gear blocks are best made by a machine shop or an online CNC service from the making sketches; the carbon plates by a CNC routing service.
- **Skills:** careful drilling and bonding of carbon; multirotor assembly and autopilot setup (PX4 or ArduPilot); handling lithium packs; for the tether set, an electrician who works with DC above 120 V.
- **Workspace:** a clean bench with dust extraction for carbon work; a non-flammable area for pack charging; a clear outdoor flight area with permission, at least 30 m across, for the first flights.

## 8. Where the numbers come from

- `cad/src/model.py`: the parametric model and its constructability checks; STEP and STL in `cad/step` and `cad/stl`.
- `cad/drawings/KWL-DWG-001` (general arrangement), `KWL-DWG-002` (folded) and `KWL-DWG-101` to `KWL-DWG-114` (making sketches).
- `docs/04-calcs/01-sizing.md` and `docs/04-calcs/sizing.py` (KWL-CAL-001).
- `bom/bom.csv` (parts, specifications and indicative prices).
- `docs/decisions/0001-trl2-review-decisions.md` and `docs/decisions/0002-design-for-construction.md`.
- `cad/src/build_plan_media.py` (every picture in this plan).

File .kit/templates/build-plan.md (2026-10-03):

---
doc_id: PRJ-BLD-001
title: Project prototype build plan
project: Project name
doc_type: Build plan
version: "0.1"
status: Draft
date: YYYY-MM-DD
author: Amish Chadha
license: CERN-OHL-S-2.0
revisions:
  - version: "0.1"
    date: YYYY-MM-DD
    author: Amish Chadha
    change: First build plan; design made constructable
---

# Project prototype build plan

**Plan, not yet built.** How to build the first proof-of-concept prototype, component by component. Building and testing to it is TRL 4 work. Decisions still to be made are kept in the design decisions register (`docs/06-design-decisions.md`), not here.

## 1. What you are building

Every component, pulled apart and numbered in build order

One short paragraph: what the prototype is, how many components, which are made and which are bought, and the main ways they are made.

## 2. What changed to make it buildable

| Component | The concept had | The buildable design has | Why |
| --- | --- | --- | --- |

## 3. Making the components

### 3.1 Component name

Making sketch

**What it is and what it is made from.**

**How to make it.**

1. Mark out ...
2. Cut ...

**How it fits the parts next to it.**

Close-up of the joint

**Check before moving on.**

## 4. Putting it together

### Step 1: ...

Step 1

## 5. First checks

| Check | Requirement | How | Pass when |
| --- | --- | --- | --- |

## 6. Safety stops

## 7. Tools, skills and workspace

## 8. Where the numbers come from

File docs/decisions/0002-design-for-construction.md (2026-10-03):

---
doc_id: KWL-DDR-002
title: Kitewright Lift design for construction
project: Kitewright Lift
doc_type: Design decision record
version: "0.1"
status: Draft
date: '2026-10-03'
author: Amish Chadha
license: CERN-OHL-S-2.0
revisions:
- version: "0.1"
  date: '2026-10-03'
  author: Amish Chadha
  change: Constructability review and the changes that make the design buildable, decided under Amish's pre-approvals of 2026-10-03
---

# 0002: Design for construction

- **Date:** 2026-10-03
- **Status:** accepted

## Context

STANDARDS section 18 asks for every part to be makeable by its stated process and to fit and fasten to its neighbours (Amish, 2026-09-30: "fix the design assumptions to match and be physically feasible"). The TRL 2 concept (KWL-PRC-001, KWL-DDR-001) named the parts but not how they are made or joined: "folding carbon arms", "a central body", "a battery bay", "wide gear". Each was worked out in `cad/src/model.py`, part by part, and checked with build123d in three states: flying with the float release, flying with the tether module, and folded for transport. The checks report no overlapping parts and no part out of contact with what holds it; the only contacts allowed are pins and bolts passing through the holes made for them, and the pack straps passing through their deck slots. Amish pre-approved every recommendation on 2026-10-03: "start with the first 14 repos from the list of 29 projects. I pre-approve the batch runs along with any recommendations you come up with. I also accept any cost overruns or variations from the assumed scope cost." and "Proceed with the remaining 15 scaffolds". No change alters what Kitewright Lift does or its pitch; the safety-related changes all take the conservative side.

## Options considered

For each problem the simplest physically sound fix was chosen; the alternatives are noted in Table 1.

## Decision

*Table 1. Changes made for construction.*

| # | Part | The concept had | The constructable design has | Why |
| --- | --- | --- | --- | --- |
| 1 | Arm fold | "Folding carbon arms", no joint | A machined aluminium hinge block at each hub corner: a 32 mm clevis slot with 7 mm cheeks, an 8 mm shoulder-bolt pivot 14 mm above the block's bottom, an 8 mm ball-lock pin, and a 10 x 10 mm stop bridge across the cheek tops 30 mm outboard of the pivot | The thrust of an arm (up to 177 N, 78 N m about the pivot) is carried by the bridge in bearing (2.6 kN, bridge bending 41 MPa); the pin only resists droop (about 610 N in a 3 g landing) |
| 2 | Arm root | Tube straight into the body | A one-piece aluminium root fitting: a 30 mm tongue in the clevis and a 48 mm collar round the tube, with a 22 x 24 mm window to save weight | Gives the pivot and lock holes a solid seat; the collar takes the tube by bonding plus two M5 cross bolts |
| 3 | Fold clearance | Not checked | Pivot 180 mm from the centre; plate corners cut at 162 mm; tongue starts 15 mm inboard of the pivot | With the pivot nearer the centre the folded root fitting cut into the bottom plate (960 mm3 overlap in the check); now 6 mm clear, and the tongue's swing stays 6 mm clear of the block's solid end |
| 4 | Central body | "A central body" | Two 3 mm carbon plates 280 mm square, 60 mm apart on the four hinge blocks and four 60 mm spacers; the Core stack between them on four rubber dampers | A light, stiff box with the avionics protected and every hole defined |
| 5 | Battery bay | "Holds two heated packs" | A 3 mm carbon deck 330 x 290 mm on four 25 mm standoffs above the top plate, two aluminium angle guides and four cam straps through deck slots | Packs sit clear of the hinge pins and outside the upper rotor discs in plan (58 mm); the straps were first placed over a standoff (overlap in the check) and were moved |
| 6 | Coaxial motor mount | Not defined | A split aluminium clamp 50 x 60 x 52 mm on the arm tip, four M4 bolts, one M5 cross bolt through the tube; a motor on its top face and one inverted on its bottom face | A solid block thick enough above the tube for the motor screws (the first block left 2 mm); coaxial gap 170 mm (0.22 propeller diameters) |
| 7 | Motor controllers | Not placed | Two controllers strapped to each arm tube near the tip | They fold with the arm; only the two power leads per arm cross the hinge, in a slack loop |
| 8 | Hub height and gear | "Wide gear" | Hub underside 500 mm up; four 20 mm carbon struts bonded into machined top and skid blocks; skids 340 mm long, 450 mm apart | The folded motors stay 32 mm above the ground and 17 mm clear of the skids; the lower rotor discs stay 99 mm clear of the struts in flight |
| 9 | Payload bay | "Clear space under the body" | The Core payload mount on the bottom plate (two slotted rails, ball-lock pin, DS-014 socket); a standard 240 x 124 x 6 mm payload plate with a lock lug and plug pad | One plate design carries every payload; the pin passes through both rails and the lug, so it cannot be half-fitted |
| 10 | Line-and-float release | "Drops a flotation device" | Payload plate, two printed saddles, a fail-closed servo pin release and a webbing sling round a 120 x 420 mm foam float with a 30 m line in a bag | Makes the drop mechanism real with bought parts; the float sits 48 mm clear of the lower rotor discs |
| 11 | Tether module | "Ground supply, reel and onboard converter" | Payload plate with a 4 kW isolated converter (200 x 110 x 65 mm), a breakaway connector under its rear, and a lead to the Core bus tether input | Fits the same rails; the breakaway parts the tether at the aircraft if it snags |
| 12 | GNSS mast | Not placed | A 16 mm carbon mast on the deck centre between the packs, 230 mm tall | Keeps the receiver clear of the power wiring and above the packs |
| 13 | Spacer and standoff positions | Not placed | On the X and Y axes, 130 mm from the centre | Clear of the hinge blocks, the Core stack and the pack straps |
| 14 | Fittings' mass | Solid blocks | Lightening pocket in each hinge block and a window in each root fitting | The first solid blocks weighed 0.62 kg (hinge) and 0.55 kg (mount) each; now 0.29 and 0.24 kg. Deeper pockets are a saving worth trying (value engineering) |

## Consequences

- `cad/src/model.py` is the constructable design; STEP and STL are regenerated; the general arrangement is KWL-DWG-001 Rev P2 and the folded arrangement KWL-DWG-002 Rev P1.
- `bom/bom.csv` gains the hinge pivot bolts, lock pins, spacers, gear blocks, pack guides and straps, the payload plates, saddles and sling.
- KWL-CAL-001 uses the model's masses; the made parts weigh 6.15 kg.
- `project.yaml` records `design_state: constructable`.
- The build plan KWL-BLD-001 describes this design; its pictures come from `cad/src/build_plan_media.py`.

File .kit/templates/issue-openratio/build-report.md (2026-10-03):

---
name: Build report
about: Tell us what happened when you built, printed or tested part of this design
title: "Build report: "
labels: build-report
---

This is a research and educational prototype, not a medical device. It is a TRL 3 concept and is not released for fabrication. If you build any part of it, you do so at your own risk. Reports help everyone.

**What you built** (part, sub-assembly or test)

**Materials, tools and settings**

**What worked**

**What did not work, with photos or measurements if you have them**

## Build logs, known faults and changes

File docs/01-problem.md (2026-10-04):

---
doc_id: KWL-PRB-001
title: Kitewright Lift problem statement
project: Kitewright Lift
doc_type: Problem statement
version: "0.3"
status: Draft
date: '2026-10-03'
author: Amish Chadha
license: CERN-OHL-S-2.0
revisions:
- version: "0.1"
  date: '2026-09-30'
  author: Amish Chadha
  change: Initial scaffold
- version: "0.2"
  date: '2026-10-03'
  author: Amish Chadha
  change: TRL 2 and 3; first co-design candidate with a checklist; open questions answered by KWL-DDR-001 and KWL-CAL-001; safety section
- version: "0.3"
  date: '2026-10-03'
  author: Amish Chadha
  change: Safety note updated for the lithium-ion ColdCell packs (decision 35A, KWL-DDR-003)
---

# Kitewright Lift problem statement

In the first hours after a flood, landslide or mountain accident, rescuers often know roughly where people are but cannot reach them. A drone that can hover, carry a little and stay up would help, but the ones that can are closed and expensive.

## The problem

Disasters that cut roads and bridges leave people stranded for hours or days: Pakistan's 2022 floods damaged about 3,500 km of roads and 150 bridges ([UN News, 2022](https://news.un.org/en/story/2022/08/1125752)), and the 2023 Sikkim outburst destroyed 13 bridges ([Mongabay India, 2023](http://india.mongabay.com/2023/10/no-early-warning-system-and-insufficient-dam-safety-turned-sikkim-flood-deadly/)). In the mountains the air itself works against aircraft: at 5,000 m standard air density is 0.736 kg/m3 and temperature -17.5 °C ([Engineering ToolBox](https://www.engineeringtoolbox.com/standard-atmosphere-d_604.html)), so a frame sized at sea level can run out of thrust and battery.

Commercial heavy-lift drones such as the DJI FlyCart 30 show what the task needs: tens of kilograms, a winch mode and a 6,000 m ceiling ([Wikipedia, DJI FlyCart](https://en.wikipedia.org/wiki/DJI_FlyCart)). Enterprise drones such as the Matrice 350 RTK carry under 1 kg at USD 14,814 ([Advexure](https://advexure.com/products/dji-matrice-350-rtk)). Both are closed. Open flight software exists in PX4 ([GitHub](https://github.com/PX4/PX4-Autopilot)), and an open payload bus in DS-014 ([Dronecode, 2021](https://dronecode.org/announcing-the-pixhawk-payload-bus-open-standard/)), but there is no open, documented multirotor frame tuned for altitude and cold that local teams can build and fit with their own payloads.

## Users and context

| User | Need | Context |
| --- | --- | --- |
| Flood and disaster response teams | Hover over a site, drop a float or line, and give a long overhead view | River and urban floods, landslides and road cuts |
| Mountain rescue teams | Carry search payloads and small supplies to 5,000 m in cold and wind | Himalaya and Karakoram expeditions and valley rescues |
| Hazard researchers | A stable hovering platform for short-range survey payloads | Glacial lakes and moraines |
| Payload builders and students | A proven frame to test payloads on the Kitewright mount | University labs and makerspaces |

## Operating environment

- Sea level to 5,000 m (design target), ambient -20 to +45 °C (-4 to +113 °F) (target).
- Wind up to about 10 m/s in normal operation (target), with valley gusts and rotor downwash over water, snow and dust.
- Take-off from rough ground, riverbanks, boats, rooftops and snow.
- Rain and spray during flood work; no mains power at site.
- Tethered operation from a vehicle or generator at a fixed point.

## Constraints

- Value-engineering target: USD 5,000 for the frame, motors, propellers and its share of core avionics, excluding payloads (a hypothetical control target, not a spending limit).
- Maximum take-off mass 25 kg or less including payload (FAA Part 107 and India Small class).
- Uses the Kitewright Core, ColdCell power bus and payload mount unchanged.
- All-electric; hybrid generator pack shelved.
- Tether power is a fixed-voltage ground supply with onboard DC-DC conversion.
- Winch module design waits for its own patent screen.
- Hardware under CERN-OHL-S-2.0; software under a licence compatible with PX4 (BSD 3-Clause) or ArduPilot (GPLv3).

## Out of scope

- Carrying people or lifting people on a line.
- Caged confined-space frames (deferred after the patent screen).
- Hybrid, fuel-cell or combustion power.
- Crop spraying and dispersal of chemicals.
- Aviation certification (FAA Part 107, EASA, India DGCA Drone Rules 2021) at this TRL; to be addressed if prototypes progress.
- Any weapon, targeting or military payload.

## Prior work

| Prior work | What it does | Gap for these users | Source |
| --- | --- | --- | --- |
| DJI FlyCart 30 | Closed heavy-lift delivery drone: 30 kg with two batteries, cargo crate or winch, 6,000 m service ceiling | Closed, large and costly; not adaptable by local teams | [link](https://en.wikipedia.org/wiki/DJI_FlyCart) |
| DJI FlyCart 30 Everest delivery tests | Carried 15 kg between 5,300 and 6,000 m at -15 to 5 °C in 2024 | Shows the need and conditions; a closed platform | [link](https://www.dji.com/media-center/announcements/dji-completes-world-first-drone-delivery-tests-on-mount-everest-en) |
| DJI Matrice 350 RTK | Enterprise multirotor, 960 g payload, 55 min flight, USD 14,814 | Small payload for the price; closed payload system | [link](https://advexure.com/products/dji-matrice-350-rtk) |
| PX4 Autopilot | Open flight control software with multirotor support, BSD 3-Clause | No open reference heavy-lift frame for altitude and cold | [link](https://github.com/PX4/PX4-Autopilot) |
| Pixhawk Payload Bus standard (DS-014) | Open payload power and data interface | Interface only; needs a frame and mount | [link](https://dronecode.org/announcing-the-pixhawk-payload-bus-open-standard/) |

## Co-design

A flood or mountain rescue organisation that already uses drones should set the mission profiles, try the line and float payload and review field handling. The first candidate to approach is the Himalayan Rescue Association, Nepal, which runs aid posts on the high trekking routes (KWL-DDR-001, item 11; not agreed).

Co-design checklist:

- [ ] Confirm the missions in order of need: float drop over water, search overhead, tethered lookout or radio relay, small supply drop.
- [ ] Confirm the payload masses that matter at sea level and at 5,000 m.
- [ ] Confirm the hover times a team would accept, with and without the tether.
- [ ] Review the folded size, the set-up steps and the carry weight with gloved hands.
- [ ] Agree the keep-out distances and drop heights over people.
- [ ] Agree a test site and the permissions the civil aviation authority requires.

## Answers to the TRL 1 open questions

Settled at TRL 2 and 3 (KWL-DDR-001, KWL-CAL-001):

- **Rotor layout.** A coaxial X8: four folding arms with a motor above and below each tip, 30 inch propellers. Losing one motor leaves its partner on the same arm.
- **Winch.** Not designed until its own patent screen is done; the payload bay leaves room for it.
- **Tether.** A fixed 400 V DC ground supply, a 60 m tether of two 0.75 mm2 conductors and a 4 kW onboard converter; about 3.3 kW from the ground for a tethered hover (estimate).
- **Payload at 5,000 m.** On paper the aircraft has a thrust to weight of 1.94 at 5,000 m and -20 C with 2 kg; AltiRig data will confirm it.
- **First high-altitude site.** Sea-level trials first, then the Khumbu region of Nepal with the co-design candidate, as the first candidate (not agreed), with civil aviation permission.

## Safety

> **Safety:** Kitewright Lift is a 25 kg class aircraft with eight 30 inch propellers, lithium-ion packs (ColdCell's variant for Lift, decision 35A), a 400 V tether and suspended loads. Spinning propellers can kill; packs can burn after a crash or a cold charge; the tether carries a dangerous voltage; a dropped load or a downwash blast can hurt people below. It is an open engineering reference, not certified aviation equipment, for civilian use only. Fly only where local rules allow, never over or near uninvolved people, and never carry or lift a person.

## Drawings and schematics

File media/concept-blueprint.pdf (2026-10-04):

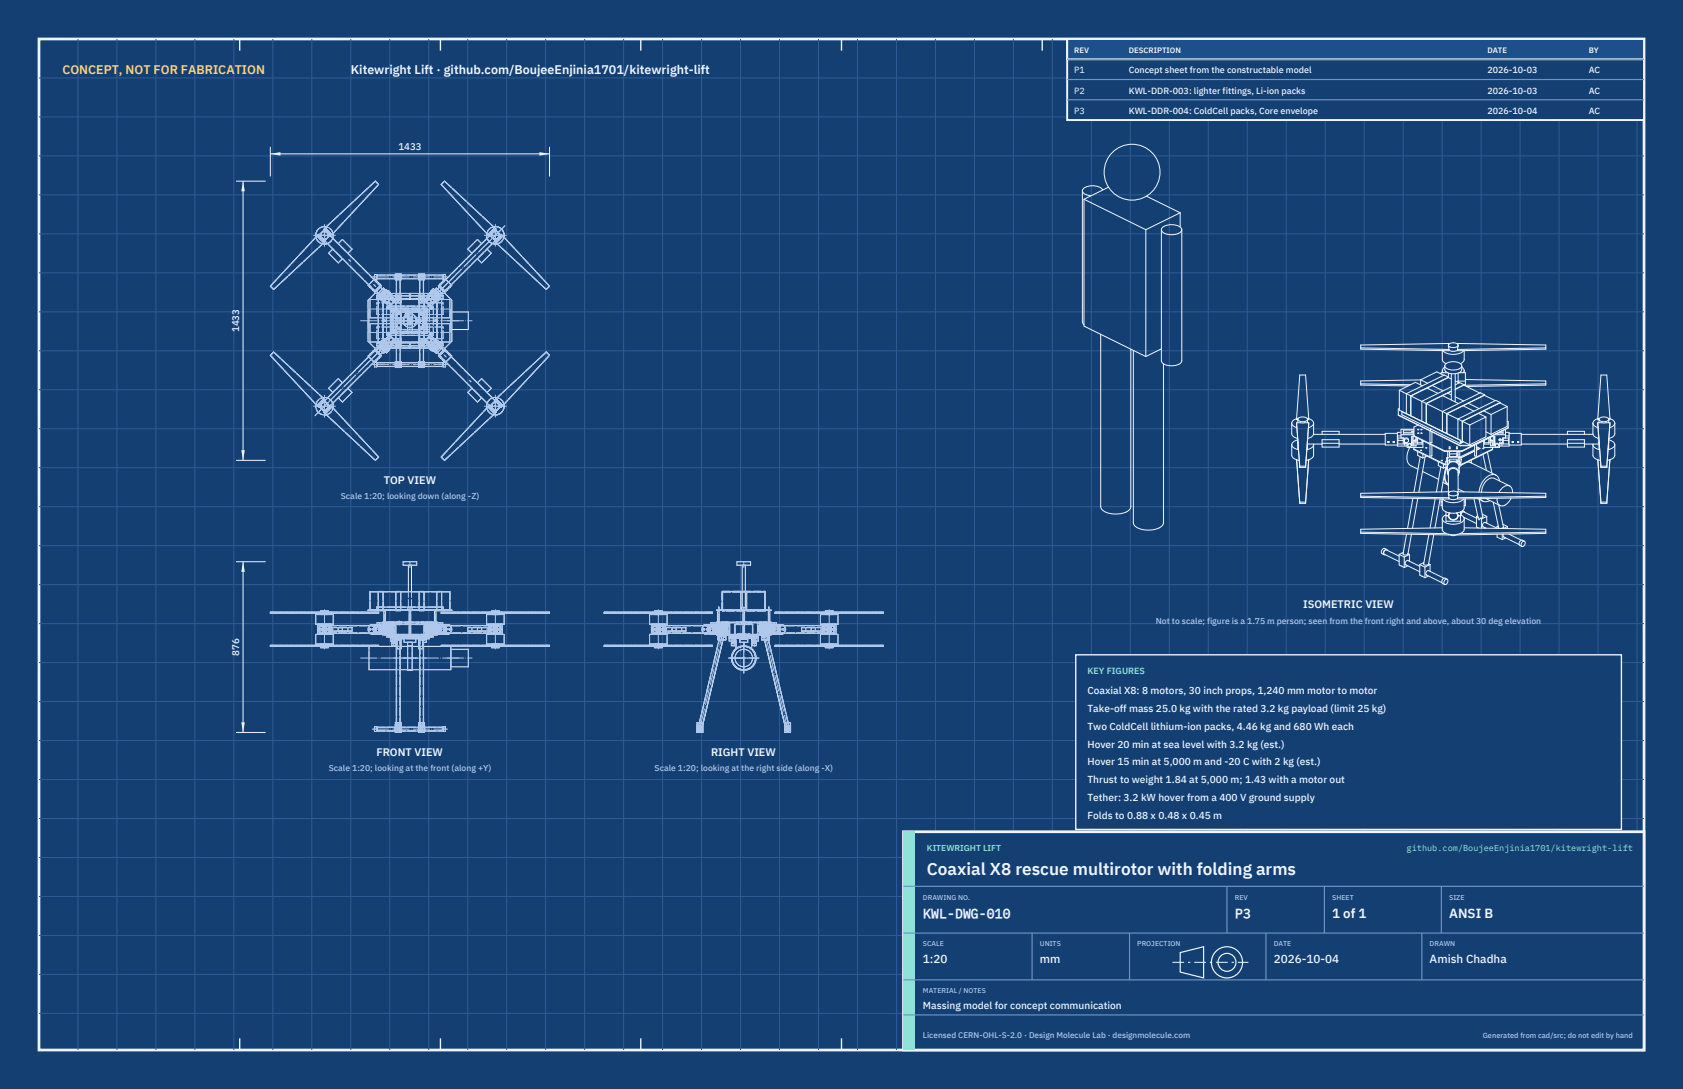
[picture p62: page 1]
CONCEPT, NOT FOR FABRICATION; Kitewright Lift · github.com/BoujeeEnjinia1701/kitewright-lift; FRONT VIEW; TOP VIEW; RIGHT VIEW; ISOMETRIC VIEW; REV; DESCRIPTION; DATE; Concept sheet from the constructable model; KWL-DDR-003: lighter fittings, Li-ion packs; KWL-DDR-004: ColdCell packs, Core envelope; KITEWRIGHT LIFT; github.com/BoujeeEnjinia1701/kitewright-lift; DRAWING NO. KWL-DWG-010; REV P3; SHEET 1 of 1; SIZE ANSI B; SCALE 1:20; UNITS mm; PROJECTION; DRAWN Amish Chadha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

Scale 1:20; looking down (along -Z)

Not to scale; figure is a 1.75 m person; seen from the front right and above, about 30 deg elevation

KEY FIGURES
Coaxial X8: 8 motors, 30 inch props, 1,240 mm motor to motor
Take-off mass 25.0 kg with the rated 3.2 kg payload (limit 25 kg)
Two ColdCell lithium-ion packs, 4.46 kg and 680 Wh each
Hover 20 min at sea level with 3.2 kg (est.)
Hover 15 min at 5,000 m and -20 C with 2 kg (est.)
Thrust to weight 1.84 at 5,000 m; 1.43 with a motor out
Tether: 3.2 kW hover from a 400 V ground supply
Folds to 0.88 x 0.48 x 0.45 m

Scale 1:20; looking at the front (along +Y)

Scale 1:20; looking at the right side (along -X)

Coaxial X8 rescue multirotor with folding arms

MATERIAL / NOTES
Massing model for concept communication

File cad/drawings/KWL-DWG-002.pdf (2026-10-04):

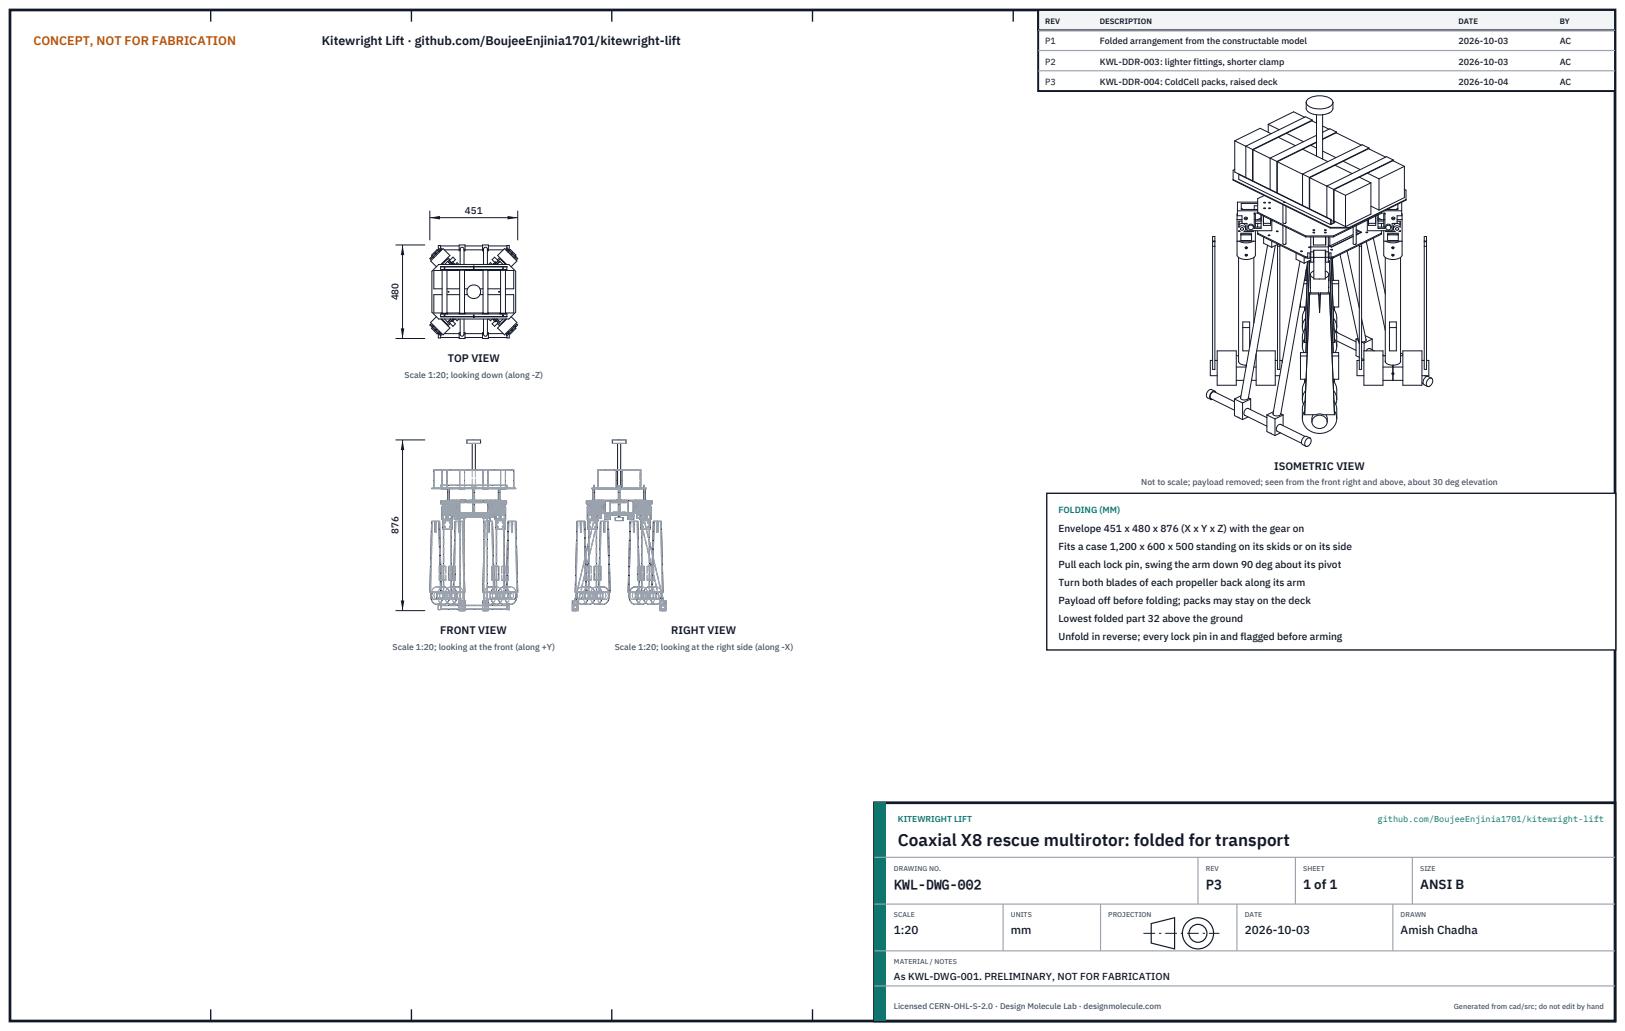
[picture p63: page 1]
CONCEPT, NOT FOR FABRICATION; Kitewright Lift · github.com/BoujeeEnjinia1701/kitewright-lift; FRONT VIEW; TOP VIEW; RIGHT VIEW; ISOMETRIC VIEW; REV; DESCRIPTION; DATE; Folded arrangement from the constructable model; KWL-DDR-003: lighter fittings, shorter clamp; KWL-DDR-004: ColdCell packs, raised deck; KITEWRIGHT LIFT; github.com/BoujeeEnjinia1701/kitewright-lift; DRAWING NO. KWL-DWG-002; REV P3; SHEET 1 of 1; SIZE ANSI B; SCALE 1:20; UNITS mm; PROJECTION; DRAWN Amish Chadha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

Scale 1:20; looking down (along -Z)

Not to scale; payload removed; seen from the front right and above, about 30 deg elevation

FOLDING (MM)
Envelope 451 x 480 x 876 (X x Y x Z) with the gear on
Fits a case 1,200 x 600 x 500 standing on its skids or on its side
Pull each lock pin, swing the arm down 90 deg about its pivot
Turn both blades of each propeller back along its arm
Payload off before folding; packs may stay on the deck
Lowest folded part 32 above the ground
Unfold in reverse; every lock pin in and flagged before arming

Scale 1:20; looking at the front (along +Y)

Scale 1:20; looking at the right side (along -X)

Coaxial X8 rescue multirotor: folded for transport

MATERIAL / NOTES
As KWL-DWG-001. PRELIMINARY, NOT FOR FABRICATION

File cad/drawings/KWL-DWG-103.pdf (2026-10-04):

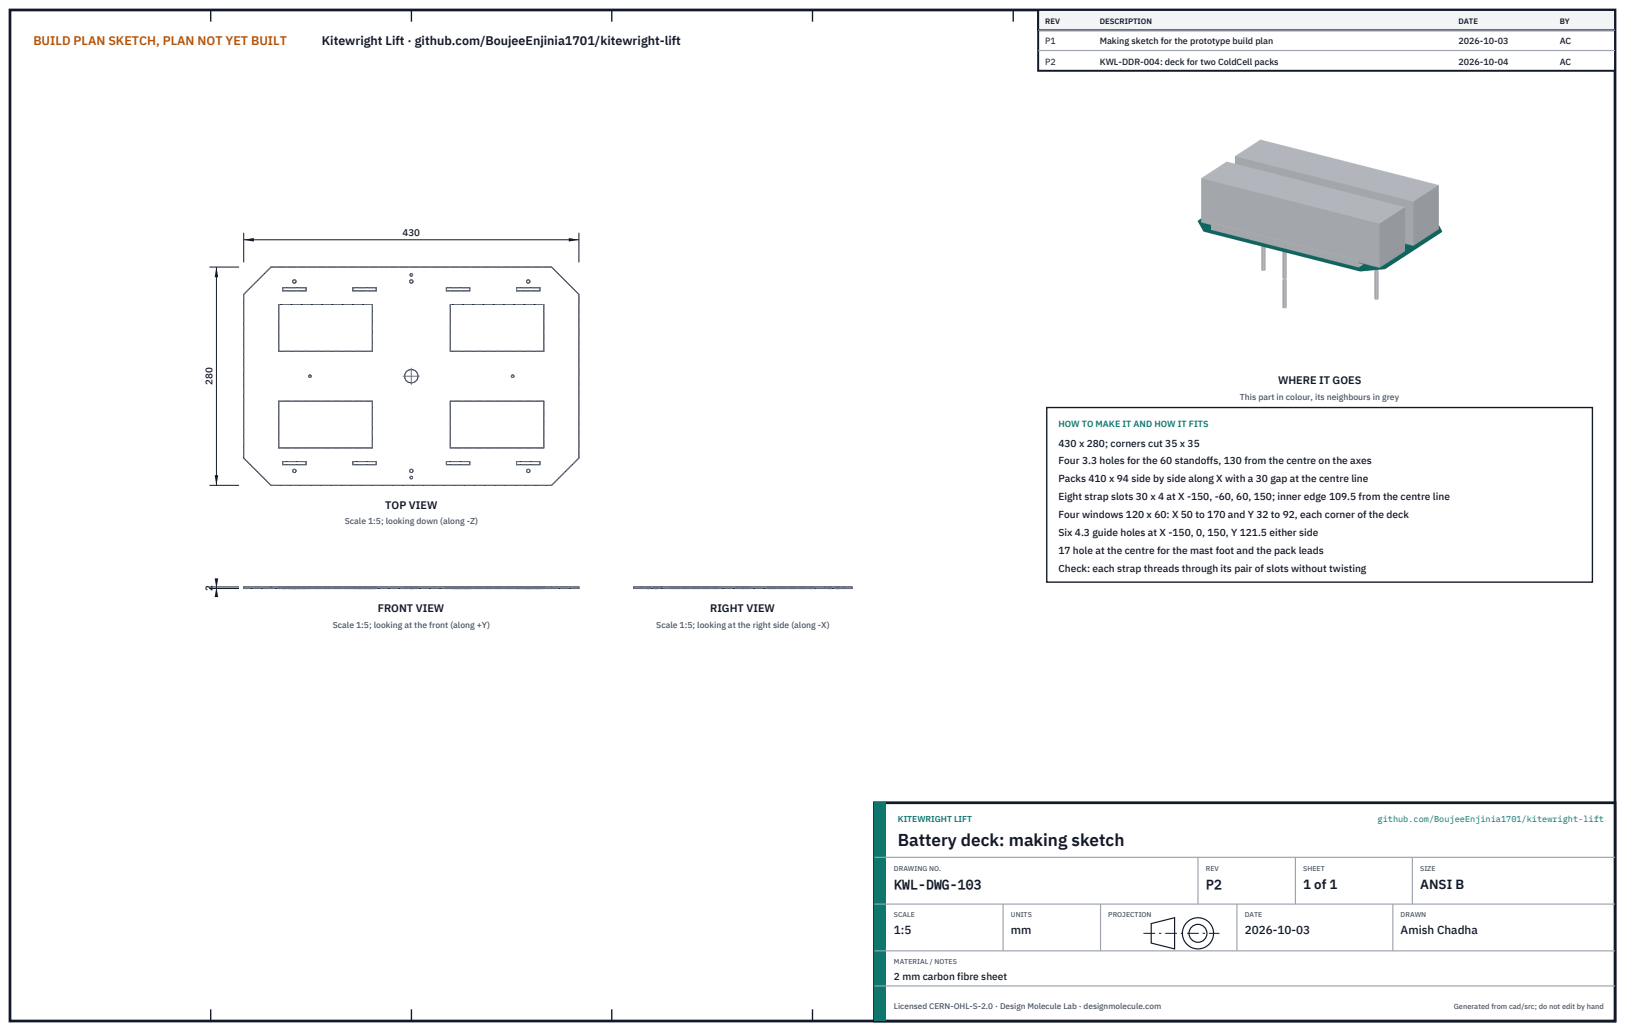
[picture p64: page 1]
BUILD PLAN SKETCH, PLAN NOT YET BUILT; Kitewright Lift · github.com/BoujeeEnjinia1701/kitewright-lift; FRONT VIEW; TOP VIEW; RIGHT VIEW; REV; DESCRIPTION; DATE; Making sketch for the prototype build plan; KWL-DDR-004: deck for two ColdCell packs; KITEWRIGHT LIFT; github.com/BoujeeEnjinia1701/kitewright-lift; DRAWING NO. KWL-DWG-103; REV P2; SHEET 1 of 1; SIZE ANSI B; SCALE 1:5; UNITS mm; PROJECTION; DRAWN Amish Chadha; Licensed CERN-OHL-S-2.0 · Design Molecule Lab · designmolecule.com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

WHERE IT GOES

This part in colour, its neighbours in grey

HOW TO MAKE IT AND HOW IT FITS
430 x 280; corners cut 35 x 35
Four 3.3 holes for the 60 standoffs, 130 from the centre on the axes
Packs 410 x 94 side by side along X with a 30 gap at the centre line
Eight strap slots 30 x 4 at X -150, -60, 60, 150; inner edge 109.5 from the centre line
Four windows 120 x 60: X 50 to 170 and Y 32 to 92, each corner of the deck
Six 4.3 guide holes at X -150, 0, 150, Y 121.5 either side
17 hole at the centre for the mast foot and the pack leads
Check: each strap threads through its pair of slots without twisting

Scale 1:5; looking down (along -Z)

Scale 1:5; looking at the front (along +Y)

Scale 1:5; looking at the right side (along -X)

Battery deck: making sketch

MATERIAL / NOTES
2 mm carbon fibre sheet

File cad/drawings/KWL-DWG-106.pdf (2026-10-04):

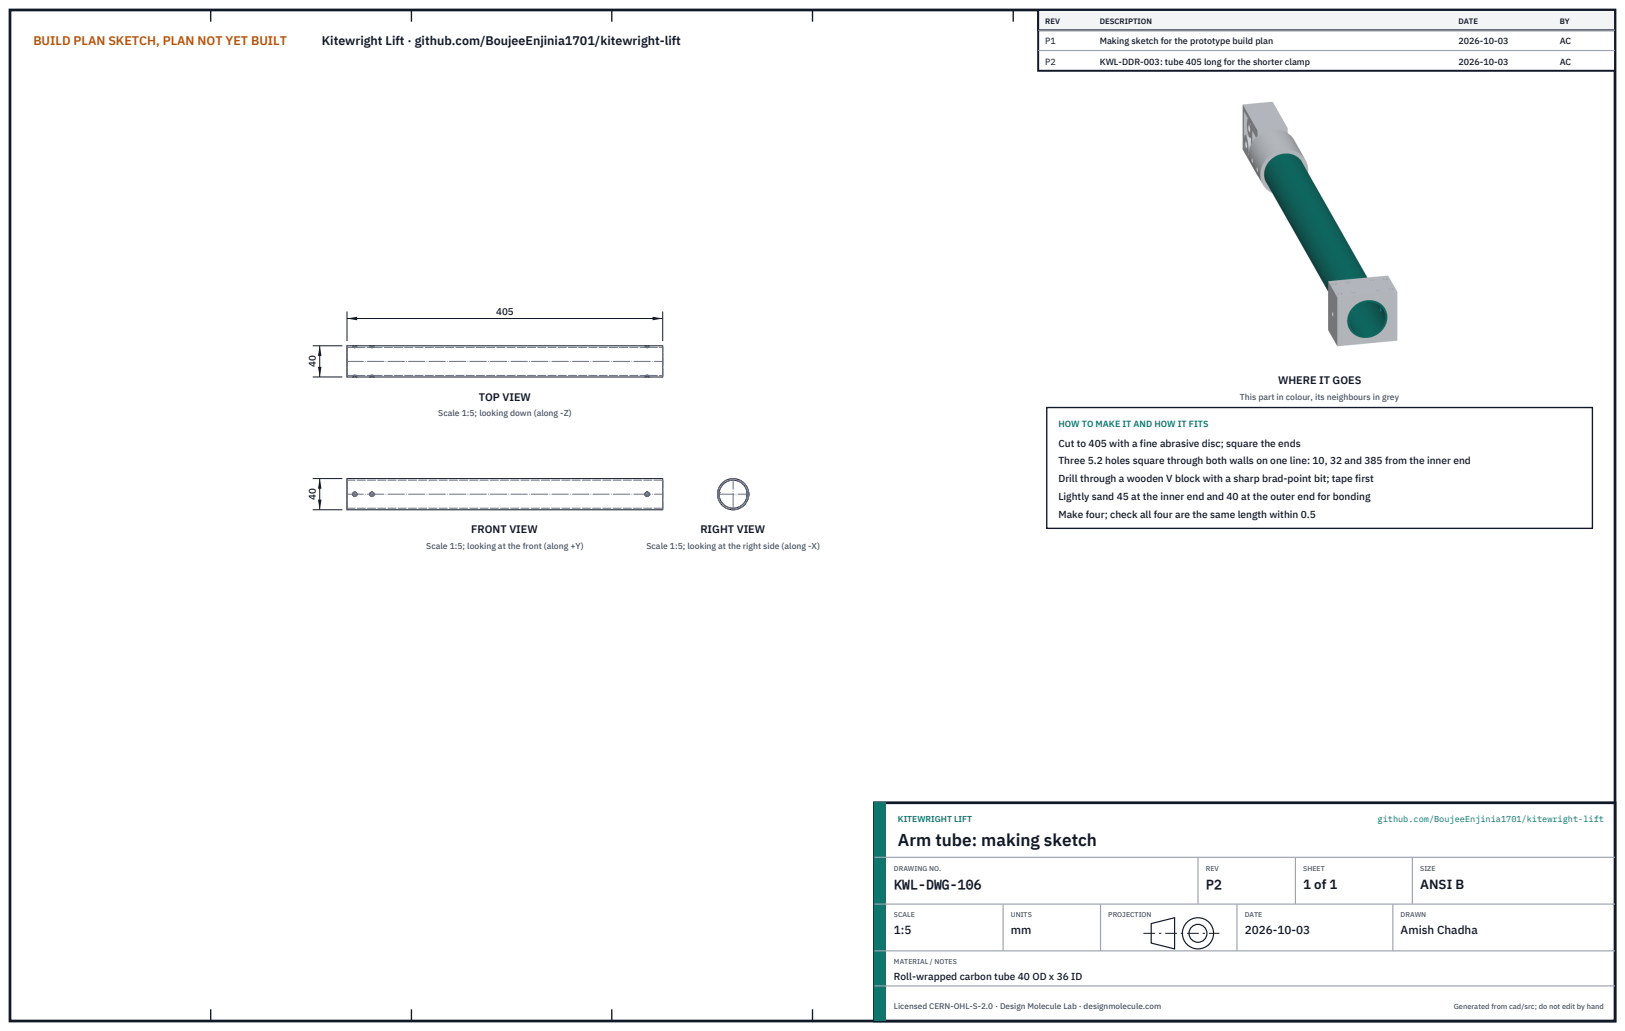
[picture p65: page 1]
BUILD PLAN SKETCH, PLAN NOT YET BUILT; Kitewright Lift · github.com/BoujeeEnjinia1701/kitewright-lift; FRONT VIEW; TOP VIEW; RIGHT VIEW; REV; DESCRIPTION; DATE; Making sketch for the prototype build plan; KWL-DDR-003: tube 405 long for the shorter clamp; KITEWRIGHT LIFT; github.com/BoujeeEnjinia1701/kitewright-lift; DRAWING NO. KWL-DWG-106; REV P2; SHEET 1 of 1; SIZE ANSI B; SCALE 1:5; UNITS mm; PROJECTION; DRAWN Amish Chadha; Licensed CERN-OHL-S-2.0 · Design Molecule Lab · designmolecule.com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

WHERE IT GOES

This part in colour, its neighbours in grey

Scale 1:5; looking down (along -Z)

HOW TO MAKE IT AND HOW IT FITS
Cut to 405 with a fine abrasive disc; square the ends
Three 5.2 holes square through both walls on one line: 10, 32 and 385 from the inner end
Drill through a wooden V block with a sharp brad-point bit; tape first
Lightly sand 45 at the inner end and 40 at the outer end for bonding
Make four; check all four are the same length within 0.5

Scale 1:5; looking at the front (along +Y)

Scale 1:5; looking at the right side (along -X)

Arm tube: making sketch

MATERIAL / NOTES
Roll-wrapped carbon tube 40 OD x 36 ID

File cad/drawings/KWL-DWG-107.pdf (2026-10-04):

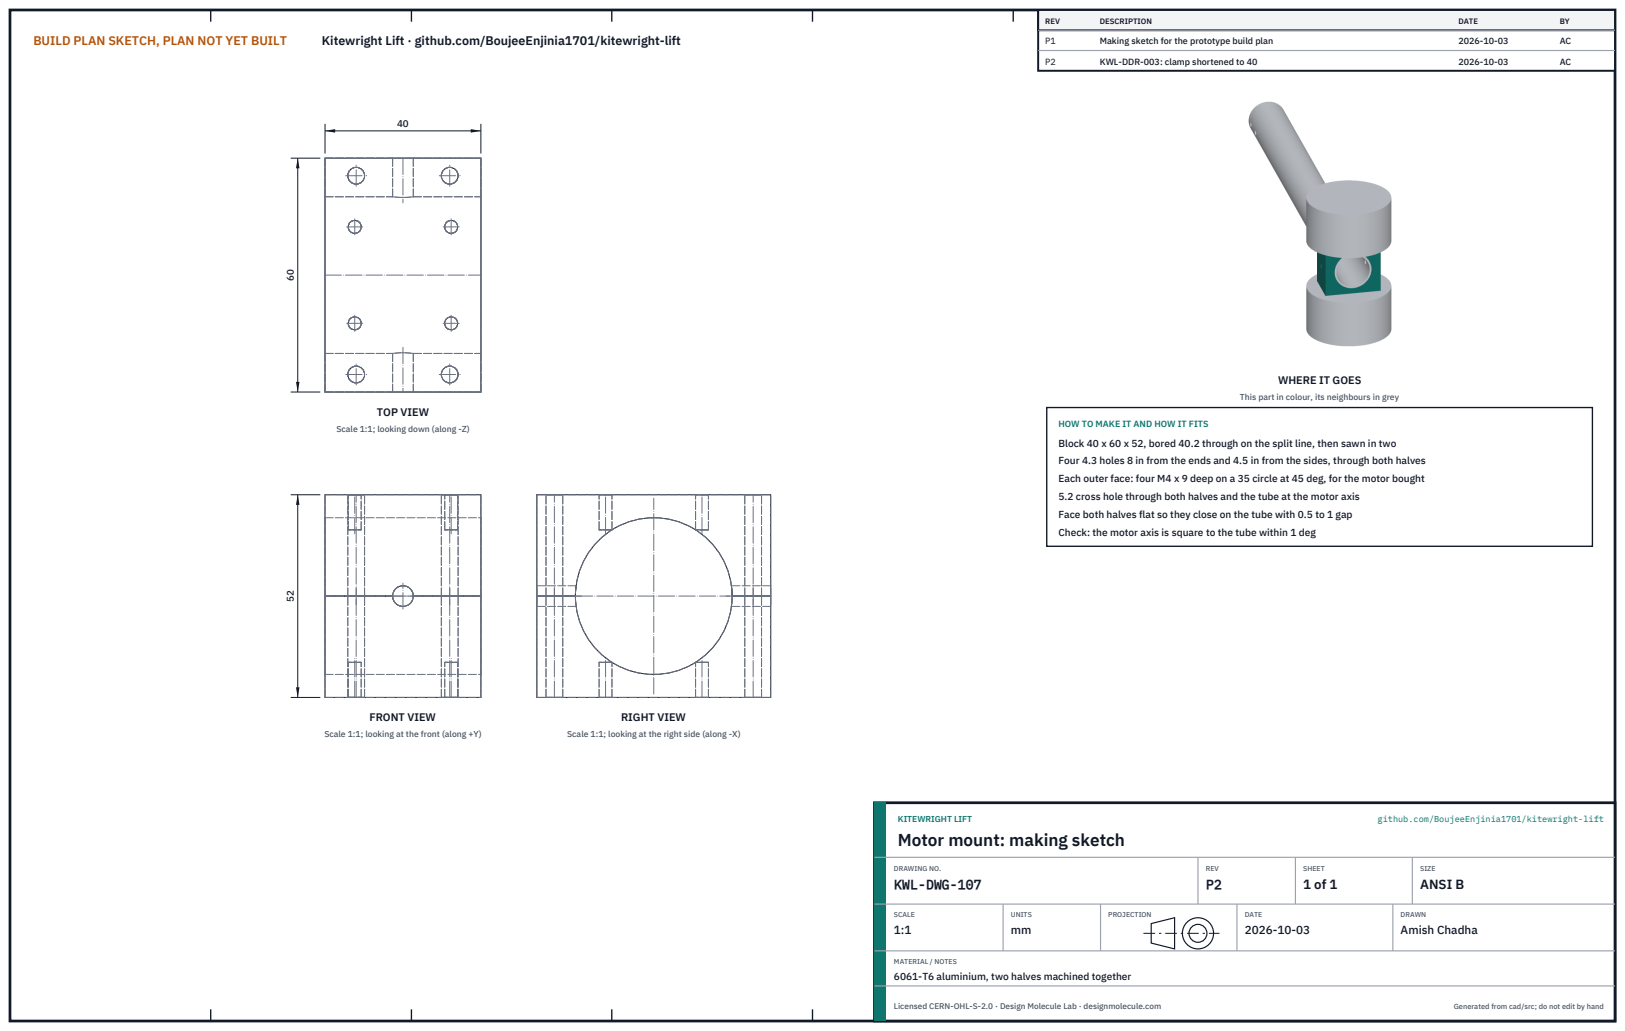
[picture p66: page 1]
BUILD PLAN SKETCH, PLAN NOT YET BUILT; Kitewright Lift · github.com/BoujeeEnjinia1701/kitewright-lift; FRONT VIEW; TOP VIEW; RIGHT VIEW; REV; DESCRIPTION; DATE; Making sketch for the prototype build plan; KWL-DDR-003: clamp shortened to 40; KITEWRIGHT LIFT; github.com/BoujeeEnjinia1701/kitewright-lift; DRAWING NO. KWL-DWG-107; REV P2; SHEET 1 of 1; SIZE ANSI B; SCALE 1:1; UNITS mm; PROJECTION; DRAWN Amish Chadha; Licensed CERN-OHL-S-2.0 · Design Molecule Lab · designmolecule.com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

WHERE IT GOES

This part in colour, its neighbours in grey

Scale 1:1; looking down (along -Z)

HOW TO MAKE IT AND HOW IT FITS
Block 40 x 60 x 52, bored 40.2 through on the split line, then sawn in two
Four 4.3 holes 8 in from the ends and 4.5 in from the sides, through both halves
Each outer face: four M4 x 9 deep on a 35 circle at 45 deg, for the motor bought
5.2 cross hole through both halves and the tube at the motor axis
Face both halves flat so they close on the tube with 0.5 to 1 gap
Check: the motor axis is square to the tube within 1 deg

Scale 1:1; looking at the front (along +Y)

Scale 1:1; looking at the right side (along -X)

Motor mount: making sketch

MATERIAL / NOTES
6061-T6 aluminium, two halves machined together

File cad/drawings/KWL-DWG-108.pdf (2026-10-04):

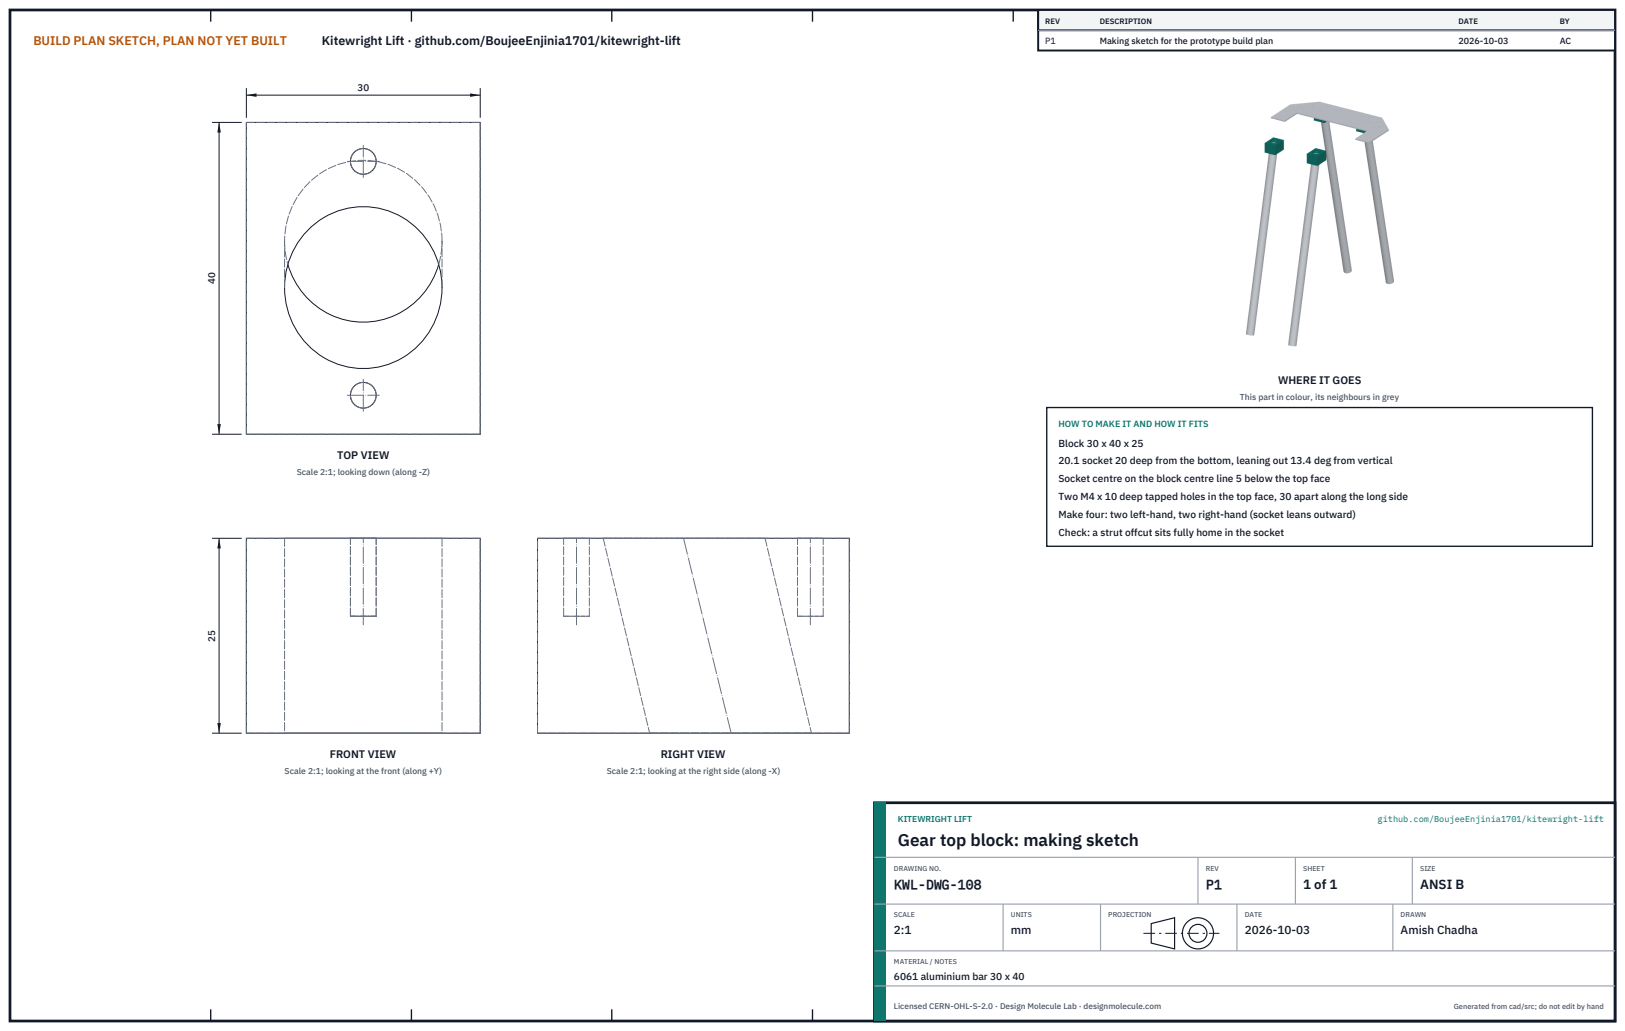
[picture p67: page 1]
BUILD PLAN SKETCH, PLAN NOT YET BUILT; Kitewright Lift · github.com/BoujeeEnjinia1701/kitewright-lift; FRONT VIEW; TOP VIEW; RIGHT VIEW; REV; DESCRIPTION; DATE; Making sketch for the prototype build plan; KITEWRIGHT LIFT; github.com/BoujeeEnjinia1701/kitewright-lift; DRAWING NO. KWL-DWG-108; REV P1; SHEET 1 of 1; SIZE ANSI B; SCALE 2:1; UNITS mm; PROJECTION; DRAWN Amish Chadha; MATERIAL / NOTES 6061 aluminium bar 30 x 40; Licensed CERN-OHL-S-2.0 · Design Molecule Lab · designmolecule.com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

WHERE IT GOES

This part in colour, its neighbours in grey

HOW TO MAKE IT AND HOW IT FITS
Block 30 x 40 x 25
20.1 socket 20 deep from the bottom, leaning out 13.4 deg from vertical
Socket centre on the block centre line 5 below the top face
Two M4 x 10 deep tapped holes in the top face, 30 apart along the long side
Make four: two left-hand, two right-hand (socket leans outward)
Check: a strut offcut sits fully home in the socket

Scale 2:1; looking down (along -Z)

Scale 2:1; looking at the front (along +Y)

Scale 2:1; looking at the right side (along -X)

Gear top block: making sketch

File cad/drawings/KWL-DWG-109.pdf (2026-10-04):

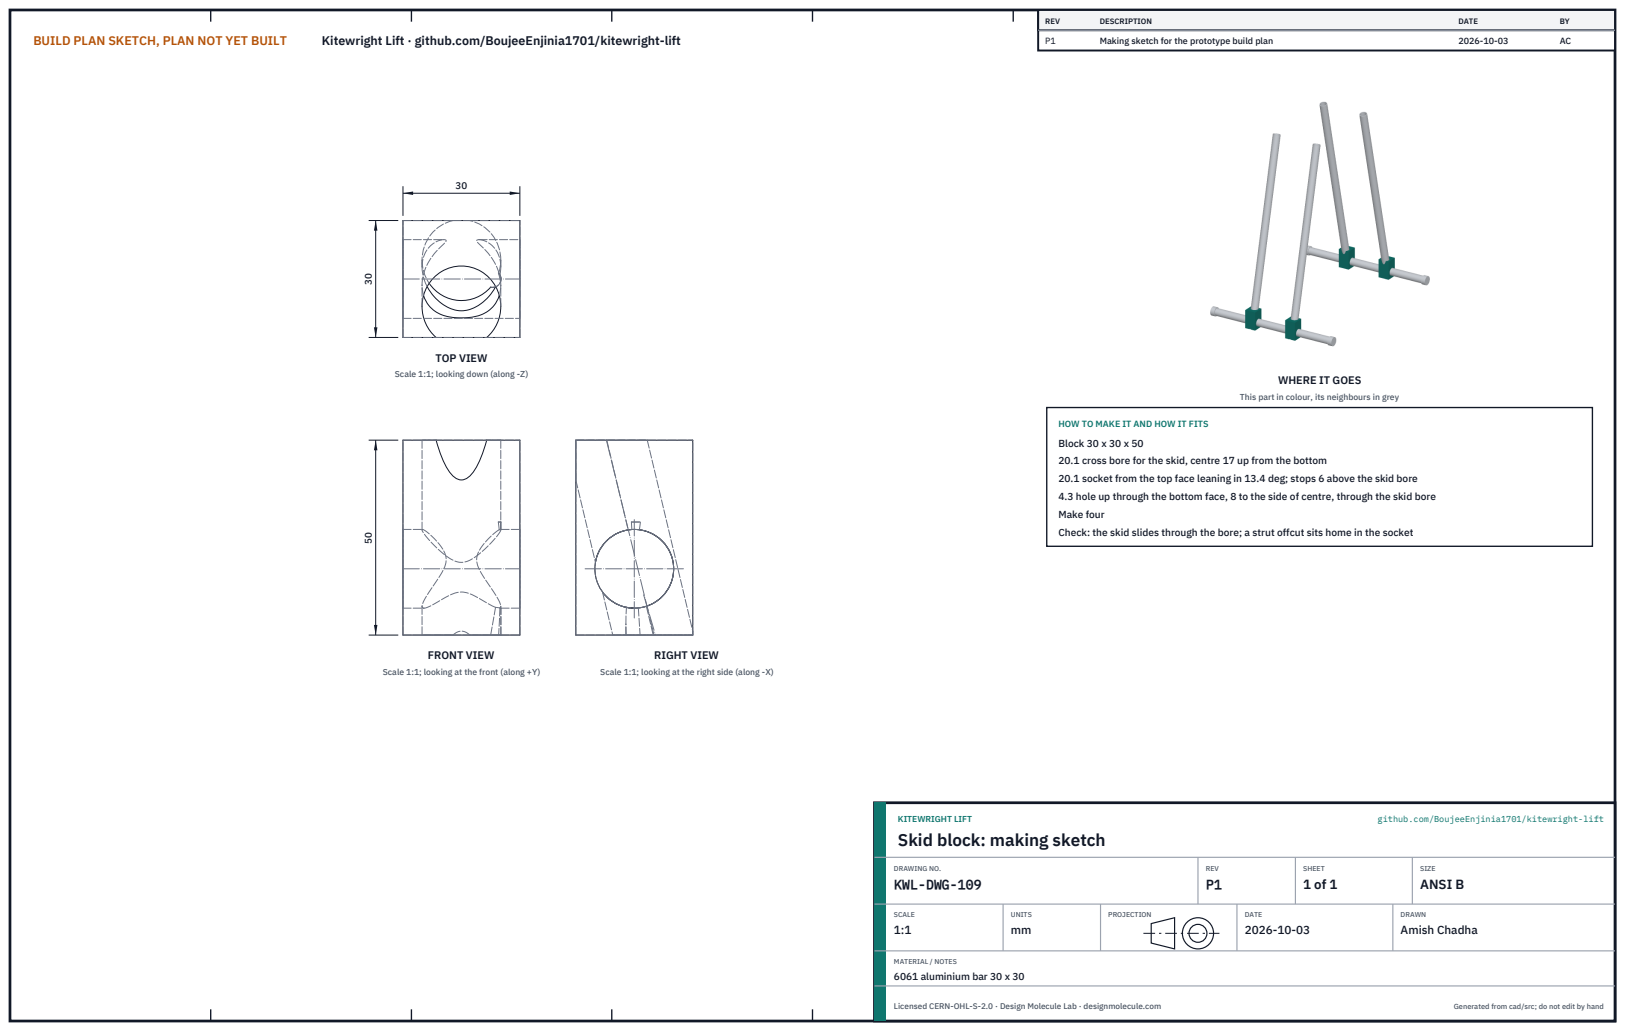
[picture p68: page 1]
BUILD PLAN SKETCH, PLAN NOT YET BUILT; Kitewright Lift · github.com/BoujeeEnjinia1701/kitewright-lift; FRONT VIEW; TOP VIEW; RIGHT VIEW; REV; DESCRIPTION; DATE; Making sketch for the prototype build plan; KITEWRIGHT LIFT; github.com/BoujeeEnjinia1701/kitewright-lift; DRAWING NO. KWL-DWG-109; REV P1; SHEET 1 of 1; SIZE ANSI B; SCALE 1:1; UNITS mm; PROJECTION; DRAWN Amish Chadha; MATERIAL / NOTES 6061 aluminium bar 30 x 30; Licensed CERN-OHL-S-2.0 · Design Molecule Lab · designmolecule.com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

Scale 1:1; looking down (along -Z)

WHERE IT GOES

This part in colour, its neighbours in grey

HOW TO MAKE IT AND HOW IT FITS
Block 30 x 30 x 50
20.1 cross bore for the skid, centre 17 up from the bottom
20.1 socket from the top face leaning in 13.4 deg; stops 6 above the skid bore
4.3 hole up through the bottom face, 8 to the side of centre, through the skid bore
Make four
Check: the skid slides through the bore; a strut offcut sits home in the socket

Scale 1:1; looking at the front (along +Y)

Scale 1:1; looking at the right side (along -X)

Skid block: making sketch

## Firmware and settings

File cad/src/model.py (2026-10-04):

"""Kitewright Lift parametric model (build123d), TRL 3, constructable design (KWL-DDR-002).

Run from the repo root:
    python cad/src/model.py            print derived sizes, run the constructability checks, export STEP and STL
    python cad/src/model.py --check    checks only, no export

The aircraft is a coaxial X8: four folding carbon arms on a two-plate carbon hub, a motor on top of and
a motor under each arm tip, 30 inch folding propellers. Each arm hinges on a machined aluminium clevis
block at a hub corner and folds DOWN for transport; in flight the thrust presses the arm up against a
stop bridge on the clevis, and a ball-lock pin only stops the arm drooping. The Kitewright Core stack
hangs under the bottom hub plate to the family envelope (core_envelope.py: four M4 on 220 x 130 mm, its lid
up through a 200 x 112 mm opening into the hub), two ColdCell lithium-ion packs (410 x 94 x 94 mm, 4.46 kg
each) sit side by side on a deck raised above the upper rotors, and payloads slide onto the Core's rail on
their own payload shoes. Two payload modules are modelled: the line-and-float release and the tether power
module. Interface figures: the Kitewright interface table of 2026-10-04 (docs/REVIEW.md).

Axes: X forward, Y left, Z up from the ground (the skids stand on Z = 0). The arms lie on the diagonals
at 45, 135, 225 and 315 degrees. Each arm group is built in a local frame (radial = +X, tangential = +Y)
and turned into place. Units mm. Parts marked (Core) and (ColdCell) are made to the sibling designs;
their sizes here are interface assumptions listed in docs/REVIEW.md, Cross-repo actions.
CONCEPT, NOT FOR FABRICATION.
"""
from __future__ import annotations

import math
import sys
from dataclasses import dataclass
from pathlib import Path

from build123d import (Axis, Box, Compound, Cylinder, Polyline, Pos, Rot, Solid, Vector, export_step,
                       export_stl, extrude, make_face)

sys.path.insert(0, str(Path(__file__).resolve().parent))
import core_envelope as CE  # noqa: E402

ROOT = Path(__file__).resolve().parents[2]

PARAMS = {
    # hub
    "hub_half": 140.0,        # half side of the square hub plates
    "chamfer_r": 162.0,       # corner cut, measured along the diagonal from the centre
    "plate_t": 3.0,           # carbon plate thickness
    "z_bot": 500.0,           # underside of the bottom hub plate above the ground
    "gap": 60.0,              # clear height between the plates (hinge block height)
    # hinge (local radial r, heights relative to z_bot)
    "blk_r": (125.0, 215.0),  # hinge block, radial extent
    "blk_w": 46.0,            # hinge block width (tangential)
    "slot_r0": 150.0,         # inner end of the clevis slot
    "slot_w": 32.0,           # clevis slot width
    "bridge_r": (205.0, 215.0),   # stop bridge across the top of the cheeks
    "bridge_h": 10.0,
    "pivot": (180.0, 17.0),   # pivot bolt (r, height above z_bot)
    "lock": (193.0, 40.0),    # lock pin (r, height above z_bot)
    "pin_d": 8.0,
    "tongue_r": (165.0, 230.0),
    "tongue_w": 30.0,
    "tongue_z": (5.0, 53.0),  # heights above z_bot
    # arm
    "collar_r": (230.0, 280.0),
    "collar_d": 48.0,
    "tube": (40.0, 36.0),     # carbon arm tube OD, ID
    "tube_r": (235.0, 640.0),  # outer end flush with the shortened motor clamp (decision 34A; 645 before)
    "motor_r": 620.0,         # motor axis radius from the aircraft centre
    "mount": (40.0, 60.0, 52.0),  # motor mount split clamp: radial, tangential, height (shortened from 50 by decision 34A)
    "motor": (90.0, 50.0),    # motor diameter, height
    "hub_d": (40.0, 18.0),    # propeller hub diameter, height
    "prop_d": 762.0,          # 30 inch
    "blade": (50.0, 24.0, 6.0),   # root chord, tip chord, thickness
    "esc": (70.0, 30.0, 18.0),
    "esc_r0": 470.0,
    # deck and packs
    "standoff": (8.0, 60.0),          # deck standoffs 60 mm (25 before decision 8A) so the deck and packs sit above the upper rotors
    "post_xy": 130.0,
    "deck": (430.0, 280.0, 2.0),      # re-sized for two ColdCell packs of 410 x 94 x 94 mm (decision 8A; was 330 x 290 x 3)
    "deck_chamfer": 35.0,
    "deck_windows": (50.0, 170.0, 32.0, 92.0),   # one lightening window under each pack end: |X| from, to; |Y| from, to
    "pack": (410.0, 94.0, 94.0),      # ColdCell 14S3P lithium-ion pack as drawn on CCL-DWG-002 (decision 8A): X, Y, Z
    "pack_gap": 30.0,                 # between the two packs, side by side in Y; the GNSS mast stands in the gap
    "guide": (15.0, 1.5),             # aluminium angle 15 x 15 x 1.5 (20 x 20 x 2 before decision 8A)
    "strap_w": 25.0,
    "mast": (16.0, 230.0),
    "puck": (70.0, 18.0),
    # Kitewright Core: hung under the bottom hub plate to the family envelope (core_envelope.py, decision 10A)
    "core_holes": (2.15, 13.0, 6.0, 10.0),   # top-plate clearance holes: M4 radius; boss, SMA and switch hole radii
    # landing gear
    "gear_x": 60.0,
    "strut_top": (112.0, -5.0),       # (y, height relative to z_bot)
    "strut_bot": (222.0, 33.0),       # (y, z)
    "strut_d": (20.0, 17.0),
    "skid_y": 225.0,
    "skid_z": 17.0,
    "skid_half": 170.0,
    "gtop": (30.0, 40.0, 25.0),
    "gskid": (30.0, 30.0, 50.0),
    # payloads hang from a Core payload shoe (KWC-DWG-106) and keep within the 88 mm neck
    "float": (120.0, 420.0),          # diameter, length
    "bag": (90.0, 90.0),
    "saddle_x": 55.0,                 # saddles clear of the Core's pigtail plug (x 69 to 83) and pin knobs (x -93 to -75)
    "saddle": (20.0, 80.0, 55.0),     # X, Y (inside the 88 mm neck), height under the shoe
    # tether module payload
    "conv": (200.0, 110.0, 65.0),
    "conv_posts": (8.0, 34.0),        # four aluminium posts under the shoe: diameter, length (converter below the neck zone)
    "conv_post_xy": ((-45.0, 30.0), (-45.0, -30.0), (75.0, 30.0), (75.0, -30.0)),   # this shoe is drilled for the posts
    "conv_x0": -55.0,                 # converter rear end: 20 mm ahead of the Core's pin knobs so they can be pulled
}
ARM_ANGLES = (45.0, 135.0, 225.0, 315.0)
COLLAR_BOLTS = (245.0, 267.0)
GUIDE_X = (-150.0, 0.0, 150.0)
GUIDE_LEN = 340.0          # pack guides, inside the deck's corner cuts


# ---------------------------------------------------------------- helpers
def bx(x0, x1, y0, y1, z0, z1):
    return Pos((x0 + x1) / 2, (y0 + y1) / 2, (z0 + z1) / 2) * Box(abs(x1 - x0), abs(y1 - y0), abs(z1 - z0))


def zcyl(x, y, r, z0, z1):
    return Pos(x, y, (z0 + z1) / 2) * Cylinder(r, abs(z1 - z0))


def xcyl(y, z, r, x0, x1):
    return Pos((x0 + x1) / 2, y, z) * Rot(0, 90, 0) * Cylinder(r, abs(x1 - x0))


def ycyl(x, z, r, y0, y1):
    return Pos(x, (y0 + y1) / 2, z) * Rot(90, 0, 0) * Cylinder(r, abs(y1 - y0))


def rod(a, b, r):
    a, b = Vector(*a), Vector(*b)
    d = b - a
    L = d.length
    c = Cylinder(r, L)
    z = Vector(0, 0, 1)
    ax = z.cross(d)
    ang = math.degrees(math.acos(max(-1.0, min(1.0, z.dot(d) / L))))
    if ax.length > 1e-9:
        c = c.rotate(Axis((0, 0, 0), (ax.X, ax.Y, ax.Z)), ang)
    return Pos(*((a + b) * 0.5)) * c


def prism_xy(points, z0, z1):
    face = make_face(Polyline(*[(x, y, z0) for x, y in points], close=True))
    return extrude(face, z1 - z0)


def fuse(shapes):
    out = shapes[0]
    for s in shapes[1:]:
        out = out + s
    return out


def turn(shape, deg):
    return Rot(0, 0, deg) * shape


def fold_about(shape, P, deg=90.0):
    """Swing an arm-group shape (local frame) tip-down about the hinge pivot."""
    r, h = P["pivot"]
    z = P["z_bot"] + h
    return Pos(r, 0, z) * Rot(0, deg, 0) * Pos(-r, 0, -z) * shape


# ---------------------------------------------------------------- derived sizes
def derived(P=PARAMS):
    zb, t = P["z_bot"], P["plate_t"]
    z_arm = zb + sum(P["tongue_z"]) / 2
    D = {
        "z_bot_top": zb + t,
        "z_top": zb + t + P["gap"],
        "z_top_top": zb + 2 * t + P["gap"],
        "z_arm": z_arm,
        "z_pivot": zb + P["pivot"][1],
        "z_deck": zb + 2 * t + P["gap"] + P["standoff"][1],
        "z_upper_prop": z_arm + P["mount"][2] / 2 + P["motor"][1] + P["hub_d"][1] / 2,
        "z_lower_prop": z_arm - P["mount"][2] / 2 - P["motor"][1] - P["hub_d"][1] / 2,
        "wheelbase": 2 * P["motor_r"],
        "tip_gap": P["motor_r"] * math.sqrt(2) - P["prop_d"],
        "coax_gap": P["mount"][2] + 2 * P["motor"][1] + P["hub_d"][1],
        "arm_len": P["motor_r"] - P["pivot"][0],
        "stop_lever": (P["bridge_r"][0] + P["bridge_r"][1]) / 2 - P["pivot"][0],
        "lock_lever": math.hypot(P["lock"][0] - P["pivot"][0], P["lock"][1] - P["pivot"][1]),
    }
    D["z_deck_top"] = D["z_deck"] + P["deck"][2]
    D["z_pack_top"] = D["z_deck_top"] + P["pack"][2]
    D["z_mast_top"] = D["z_deck_top"] + P["mast"][1] + P["puck"][1]
    D["coax_ratio"] = (D["z_upper_prop"] - D["z_lower_prop"]) / P["prop_d"]
    D["strut_len"] = math.dist((P["gear_x"], P["strut_top"][0], zb + P["strut_top"][1]),
                               (P["gear_x"], P["strut_bot"][0], P["strut_bot"][1]))
    return D


# ---------------------------------------------------------------- hub
def plate_outline(P=PARAMS):
    h = P["hub_half"]
    c = P["chamfer_r"] * math.sqrt(2) - h   # where the chamfer meets the side
    return [(h, -c), (h, c), (c, h), (-c, h), (-h, c), (-h, -c), (-c, -h), (c, -h)]


def block_bolt_holes(P=PARAMS):
    """Four M4 holes per hinge block, in local (r, t)."""
    return [(131.0, -15.0), (131.0, 15.0), (144.0, -15.0), (144.0, 15.0)]


def hub_posts(P=PARAMS):
    a = P["post_xy"]
    return [(a, 0.0), (-a, 0.0), (0.0, a), (0.0, -a)]


def core_z(P=PARAMS):
    """Top face of the Core plate: the deck (bottom hub plate) underside sits on the 8 mm corner spacers."""
    return P["z_bot"] - CE.CORE["spacer"][2]


def gear_bolt_xy(P=PARAMS):
    gx, yt = P["gear_x"], P["strut_top"][0]
    return [(sx * gx, sy * (yt + dy)) for sx in (-1, 1) for sy in (-1, 1) for dy in (-15.0, 15.0)]


def local_to_xy(r, t, ang):
    a = math.radians(ang)
    return r * math.cos(a) - t * math.sin(a), r * math.sin(a) + t * math.cos(a)


def hub_plate(P=PARAMS, top=False):
    zb, t = P["z_bot"], P["plate_t"]
    z0 = zb + t + P["gap"] if top else zb
    pl = prism_xy(plate_outline(P), z0, z0 + t)
    holes = []
    for ang in ARM_ANGLES:
        for r, tt in block_bolt_holes(P):
            x, y = local_to_xy(r, tt, ang)
            holes.append((x, y, 2.15))
    for x, y in hub_posts(P):
        holes.append((x, y, 1.65))
    m4, rb, rs, rw = P["core_holes"]
    C = CE.CORE
    if top:
        holes.append((0.0, 0.0, 15.0))                       # cable pass to the deck and mast
        holes.append((C["boss"][0], C["boss"][1], rb))       # the Core lid's GNSS mast boss stands up through the plate
        holes += [(x, y, rs) for x, y in C["sma"][0]]        # SMA bulkheads (antennas on extension leads, decision 10A)
        holes.append((C["switch"][0], C["switch"][1], rw))   # safety switch, pressed through the plate
    else:
        holes += [(x, y, 2.15) for x, y in gear_bolt_xy(P)]
        holes += [(x, y, m4) for x, y in CE.frame_points()]  # the Core's four M4 hard points, 220 x 130 mm
    for x, y, r in holes:
        pl = pl - zcyl(x, y, r, z0 - 1, z0 + t + 1)
    if not top:
        ox, oy = C["deck_opening"]
        pl = pl - bx(-ox / 2, ox / 2, -oy / 2, oy / 2, z0 - 1, z0 + t + 1)   # opening for the Core lid
    return pl


def hinge_block_local(P=PARAMS):
    zb = P["z_bot"]
    z0, z1 = zb + P["plate_t"], zb + P["plate_t"] + P["gap"]
    r0, r1 = P["blk_r"]
    w, sw = P["blk_w"] / 2, P["slot_w"] / 2
    b = bx(r0, r1, -w, w, z0, z1)
    b = b - bx(P["slot_r0"], r1 + 1, -sw, sw, z0 - 1, z1 - P["bridge_h"])           # slot, open below
    b = b - bx(P["slot_r0"], P["bridge_r"][0], -sw, sw, z1 - P["bridge_h"] - 1, z1 + 1)  # slot, open above inboard of the bridge
    b = b - bx(128.0, 147.0, -8.0, 8.0, z0 - 1, z1 + 1)                              # lightening pocket
    # decision 34A (2026-10-03): deeper lightening, leaving 4 to 5 mm walls and webs round every hole
    for s in (-1, 1):
        b = b - bx(128.0, 147.0, s * 12.0, s * (w + 1), z0 + 16, z1 - 16)               # side pockets in the bolting end
    b = b - bx(153.0, 171.0, -w - 1, w + 1, zb + 10, zb + 56)                         # window through both cheeks
    b = b - bx(190.0, r1 + 1, -w - 1, w + 1, z0 - 1, zb + 25)                         # outboard lower corner of the cheeks
    b = b - bx(203.0, r1 + 1, -w - 1, w + 1, zb + 24, zb + 48)                        # under the stop bridge, outboard of the lock boss (15 mm top rail left)
    pr, ph = P["pivot"]
    lr, lh = P["lock"]
    b = b - ycyl(pr, zb + ph, P["pin_d"] / 2 + 0.05, -w - 1, w + 1)
    b = b - ycyl(lr, zb + lh, P["pin_d"] / 2 + 0.1, -w - 1, w + 1)
    for r, tt in block_bolt_holes(P):
        b = b - zcyl(r, tt, 1.65, z0 - 1, z0 + 12) - zcyl(r, tt, 1.65, z1 - 12, z1 + 1)
    return b


def tongue_local(P=PARAMS):
    """Arm root fitting: tongue in the clevis and a collar round the arm tube (one machined part)."""
    zb = P["z_bot"]
    za0, za1 = zb + P["tongue_z"][0], zb + P["tongue_z"][1]
    z_arm = (za0 + za1) / 2
    w = P["tongue_w"] / 2
    t = bx(P["tongue_r"][0], P["tongue_r"][1], -w, w, za0, za1)
    c0, c1 = P["collar_r"]
    t = t + xcyl(0, z_arm, P["collar_d"] / 2, c0, c1)
    t = t - xcyl(0, z_arm, P["tube"][0] / 2 + 0.1, P["tube_r"][0] - 1, c1 + 1)
    pr, ph = P["pivot"]
    lr, lh = P["lock"]
    t = t - ycyl(pr, zb + ph, P["pin_d"] / 2 + 0.05, -w - 1, w + 1)
    t = t - ycyl(lr, zb + lh, P["pin_d"] / 2 + 0.1, -w - 1, w + 1)
    t = t - bx(206.0, 228.0, -w - 1, w + 1, z_arm - 14, z_arm + 14)                   # lightening window (24 tall before decision 34A)
    # decision 34A (2026-10-03): side pockets 12.5 deep each side leave a 5 mm web, with 5 mm bosses round the holes
    bosses = ycyl(pr, zb + ph, 9.5, -w - 2, w + 2) + ycyl(lr, zb + lh, 9.5, -w - 2, w + 2)
    for s in (-1, 1):
        t = t - (bx(170.0, 201.0, s * 2.5, s * (w + 1), za0 + 5, za1 - 5) - bosses)
    for r in COLLAR_BOLTS:
        t = t - ycyl(r, z_arm, 2.65, -30, 30)
    return t


def tube_local(P=PARAMS):
    z_arm = derived(P)["z_arm"]
    o, i = P["tube"]
    r0, r1 = P["tube_r"]
    tb = xcyl(0, z_arm, o / 2, r0, r1) - xcyl(0, z_arm, i / 2, r0 - 1, r1 + 1)
    for r in COLLAR_BOLTS + (P["motor_r"],):
        tb = tb - ycyl(r, z_arm, 2.65, -40, 40)
    return tb


def clamp_bolts(P=PARAMS):
    rc = P["motor_r"]
    mr, mt, _ = P["mount"]
    return [(rc + dr, s * (mt / 2 - 4.5)) for dr in (-mr / 2 + 8, mr / 2 - 8) for s in (-1, 1)]


def motor_holes(P=PARAMS):
    rc = P["motor_r"]
    return [(rc + 17.5 * math.cos(math.radians(45 + 90 * k)), 17.5 * math.sin(math.radians(45 + 90 * k))) for k in range(4)]


def mount_local(P=PARAMS):
    """Motor mount: a split clamp round the arm tip, two halves joined by four M4 bolts; each half
    carries one motor on its outer face."""
    z_arm = derived(P)["z_arm"]
    mr, mt, mh = P["mount"]
    rc = P["motor_r"]
    halves = []
    for s in (1, -1):
        z0, z1 = (z_arm + 0.0, z_arm + mh / 2) if s > 0 else (z_arm - mh / 2, z_arm - 0.0)
        h = bx(rc - mr / 2, rc + mr / 2, -mt / 2, mt / 2, z0, z1)
        h = h - xcyl(0, z_arm, P["tube"][0] / 2 + 0.1, rc - mr / 2 - 1, rc + mr / 2 + 1)
        for x, y in clamp_bolts(P):
            h = h - zcyl(x, y, 2.15, z_arm - mh, z_arm + mh)
        for x, y in motor_holes(P):
            zf = z_arm + s * mh / 2
            h = h - zcyl(x, y, 1.65, min(zf, zf - s * 9), max(zf, zf - s * 9))
        h = h - ycyl(rc, z_arm, 2.65, -mt, mt)
        halves.append(h)
    return Compound(halves)


def blade(P, z, direction, flip=False):
    """One propeller blade in the rotor plane at height z, pointing at `direction` degrees about the
    motor axis (0 = radially outward)."""
    rc = P["motor_r"]
    c0, c1, th = P["blade"]
    R = P["prop_d"] / 2
    r0 = P["hub_d"][0] / 2 - 2
    pts = [(r0, -c0 / 2), (R, -c1 / 2), (R, c1 / 2), (r0, c0 / 2)]
    b = prism_xy(pts, -th / 2, th / 2)
    return Pos(rc, 0, z) * Rot(0, 0, direction) * b


def rotor_local(P=PARAMS, upper=True, folded_blades=False):
    """Motor, propeller hub and two blades for the upper or lower rotor of an arm (local frame)."""
    D = derived(P)
    z_arm = D["z_arm"]
    mh = P["mount"][2] / 2
    md, mhgt = P["motor"]
    hd, hh = P["hub_d"]
    rc = P["motor_r"]
    s = 1 if upper else -1
    zm0 = z_arm + s * mh
    motor = zcyl(rc, 0, md / 2, min(zm0, zm0 + s * mhgt), max(zm0, zm0 + s * mhgt))
    zh0 = zm0 + s * mhgt
    hub = zcyl(rc, 0, hd / 2, min(zh0, zh0 + s * hh), max(zh0, zh0 + s * hh))
    zp = zh0 + s * hh / 2
    if folded_blades:   # both blades swung back along the arm, side by side, for transport
        blades = [Pos(0, dy, 0) * blade(P, zp, 180.0) for dy in (-14.0, 14.0)]
        blades = [b - zcyl(rc, 0, hd / 2 + 0.5, zp - 10, zp + 10) for b in blades]
    else:
        blades = [blade(P, zp, a) for a in (90.0, 270.0)]
    return motor, hub + fuse(blades)


def esc_local(P=PARAMS):
    z_arm = derived(P)["z_arm"]
    L, W, H = P["esc"]
    r0 = P["esc_r0"]
    ro = P["tube"][0] / 2
    return [bx(r0, r0 + L, s * ro, s * (ro + W), z_arm - H / 2, z_arm + H / 2) for s in (-1, 1)]


def pivot_pin_local(P=PARAMS):
    w = P["blk_w"] / 2
    pr, ph = P["pivot"]
    z = P["z_bot"] + ph
    shank = ycyl(pr, z, P["pin_d"] / 2, -w - 2, w + 2)
    head = ycyl(pr, z, 7.0, w + 2, w + 7)
    nut = ycyl(pr, z, 7.0, -w - 8, -w - 2)
    return shank + head + nut


def lock_pin_local(P=PARAMS):
    w = P["blk_w"] / 2
    lr, lh = P["lock"]
    z = P["z_bot"] + lh
    shank = ycyl(lr, z, P["pin_d"] / 2, -w - 4, w + 1)
    head = ycyl(lr, z, 9.0, w + 1, w + 9)
    return shank + head


def arm_group_local(P=PARAMS, folded_blades=False):
    """Every part that swings with the arm (local frame), by key."""
    um, ur = rotor_local(P, True, folded_blades)
    lm, lr = rotor_local(P, False, folded_blades)
    return {"arm_roots": tongue_local(P), "arm_tubes": tube_local(P), "motor_mounts": mount_local(P),
            "motors": um + lm, "props": ur + lr, "escs": fuse(esc_local(P))}


def hub_spacers(P=PARAMS):
    zb, t = P["z_bot"], P["plate_t"]
    d, h = P["standoff"]
    out = [zcyl(x, y, d / 2, zb + t, zb + t + P["gap"]) for x, y in hub_posts(P)]
    zt = zb + 2 * t + P["gap"]
    out += [zcyl(x, y, d / 2, zt, zt + h) for x, y in hub_posts(P)]
    return [s - zcyl(*xy, 1.6, 0, 2000) for s, xy in zip(out, hub_posts(P) * 2)]


# ---------------------------------------------------------------- deck, packs, mast
def pack_centres(P=PARAMS):
    """Two packs side by side in Y, long axis along X (decision 8A)."""
    py = P["pack"][1] / 2 + P["pack_gap"] / 2
    return [(0.0, -py), (0.0, py)]


def pack_half_y(P=PARAMS):
    """Outer face of the pack pair from the centre line."""
    return P["pack_gap"] / 2 + P["pack"][1]


def strap_x(P=PARAMS):
    """Four cam straps, each round both packs, clear of the mast in the gap."""
    return [-150.0, -60.0, 60.0, 150.0]


def deck(P=PARAMS):
    D = derived(P)
    L, W, t = P["deck"]
    c = P["deck_chamfer"]
    hx, hy = L / 2, W / 2
    pts = [(hx - c, -hy), (hx, -hy + c), (hx, hy - c), (hx - c, hy), (-hx + c, hy), (-hx, hy - c), (-hx, -hy + c), (-hx + c, -hy)]
    z0 = D["z_deck"]
    d = prism_xy(pts, z0, z0 + t)
    for x, y in hub_posts(P):
        d = d - zcyl(x, y, 1.65, z0 - 1, z0 + t + 1)
    py = pack_half_y(P)
    for x in strap_x(P):
        for s in (-1, 1):
            d = d - bx(x - 15, x + 15, s * (py + 0.5), s * (py + 4.5), z0 - 1, z0 + t + 1)
    gy = py + 5.0 + P["guide"][0] / 2
    for x in GUIDE_X:
        for s in (-1, 1):
            d = d - zcyl(x, s * gy, 2.15, z0 - 1, z0 + t + 1)
    d = d - zcyl(0, 0, 8.5, z0 - 1, z0 + t + 1)   # mast foot and pack leads
    wx0, wx1, wy0, wy1 = P["deck_windows"]
    for sx in (-1, 1):
        for sy in (-1, 1):
            d = d - bx(sx * wx0, sx * wx1, sy * wy0, sy * wy1, z0 - 1, z0 + t + 1)   # lightening windows under the packs
    return d


def guides(P=PARAMS):
    D = derived(P)
    a, t = P["guide"]
    z0 = D["z_deck_top"]
    py = pack_half_y(P) + 5.0
    L = GUIDE_LEN
    out = []
    for s in (-1, 1):
        y0 = s * py
        g = bx(-L / 2, L / 2, y0, y0 + s * a, z0, z0 + t) + bx(-L / 2, L / 2, y0 + s * (a - t), y0 + s * a, z0, z0 + a)
        for x in GUIDE_X:
            g = g - zcyl(x, s * (py + a / 2), 2.15, z0 - 1, z0 + t + 1)
        out.append(g)
    return out


def packs(P=PARAMS):
    D = derived(P)
    X, Y, Z = P["pack"]
    z0 = D["z_deck_top"]
    return [bx(cx - X / 2, cx + X / 2, cy - Y / 2, cy + Y / 2, z0, z0 + Z) for cx, cy in pack_centres(P)]


def straps(P=PARAMS):
    D = derived(P)
    w = P["strap_w"]
    X, _, Z = P["pack"]
    Y = 2 * pack_half_y(P)
    z0, zt = D["z_deck_top"], D["z_deck_top"] + Z
    zd = D["z_deck"]
    out = []
    for x in strap_x(P):
        top = bx(x - w / 2, x + w / 2, -Y / 2 - 1.5, Y / 2 + 1.5, zt, zt + 1.5)
        sides = [bx(x - w / 2, x + w / 2, s * Y / 2, s * (Y / 2 + 1.5), zd - 1.5, zt) for s in (-1, 1)]
        under = bx(x - w / 2, x + w / 2, -Y / 2 - 1.5, Y / 2 + 1.5, zd - 1.5, zd)
        out.append(fuse([top] + sides + [under]))
    return out


def mast(P=PARAMS):
    D = derived(P)
    d, h = P["mast"]
    pd, ph = P["puck"]
    z0 = D["z_deck_top"]
    foot = zcyl(0, 0, 12.0, z0, z0 + 12)
    tube = zcyl(0, 0, d / 2, z0 + 12, z0 + h)
    return foot + tube, zcyl(0, 0, pd / 2, z0 + h, z0 + h + ph)


# ---------------------------------------------------------------- Kitewright Core to the family envelope (decision 10A)
def core_stack(P=PARAMS):
    """The Core body under the bottom hub plate: plate, corner spacers, lid (through the deck opening) and
    strain-relief bar. Returned as (body, None) for the older callers."""
    return CE.place(CE.core_body(), 0, 0, core_z(P)), None
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

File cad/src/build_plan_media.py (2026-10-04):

"""Kitewright Lift prototype build plan pictures (KWL-BLD-001, STANDARDS section 18).

Run from the repo root:  python cad/src/build_plan_media.py [overview|sheets|joints|steps ...]
With no argument it draws everything (one picture group per process is kinder to a small machine).
Every picture is drawn from cad/src/model.py, so the pictures and the model never disagree:
    docs/05-build-plan/overview.png       every component pulled apart, numbered in build order
    cad/drawings/KWL-DWG-101 to 114       making sketches for the made components
    docs/05-build-plan/joint-NN.png       close-ups of the joints that need explaining
    docs/05-build-plan/step-NN.png        one picture per assembly step
Uses .kit/build_views.py. Single-arm pictures are drawn in the arm's own frame (arm along +X).
BUILD PLAN ILLUSTRATION, PLAN NOT YET BUILT.
"""
import math
import sys
from pathlib import Path

ROOT = Path(__file__).resolve().parents[2]
sys.path[:0] = [str(ROOT / ".kit"), str(ROOT / "cad" / "src")]
import build_views as bv  # noqa: E402
from build_views import Part  # noqa: E402
from build123d import Compound, Pos  # noqa: E402
import model as M  # noqa: E402
from model import PARAMS as P, bx, turn, fold_about, derived  # noqa: E402

OUT = ROOT / "docs" / "05-build-plan"
DWG = ROOT / "cad" / "drawings"
DATE = "2026-10-03"
D = derived(P)
ARM = 315.0                                    # the front-right arm, nearest the usual camera
U = (math.cos(math.radians(ARM)), math.sin(math.radians(ARM)))

COL = {"top_plate": "#374151", "bot_plate": "#374151", "spacers": "#9CA3AF", "hinge_blocks": "#0F766E",
       "arm_roots": "#14B8A6", "arm_tubes": "#1F2937", "motor_mounts": "#0E7490", "pivots": "#6B7280",
       "lock_pins": "#DC2626", "motors": "#6B7280", "escs": "#475569", "props": "#334155",
       "gear_tops": "#0F766E", "skid_blocks": "#0F766E", "struts": "#1F2937", "skids": "#1F2937",
       "deck": "#4B5563", "guides": "#9CA3AF", "straps": "#F59E0B", "mast": "#94A3B8", "core": "#7C3AED",
       "rails": "#A855F7", "ds014": "#A855F7", "paylock": "#DC2626", "packs": "#2563EB",
       "fr_plate": "#94A3B8", "saddles": "#CBD5E1", "release": "#1D4ED8", "sling": "#FACC15", "float": "#F97316",
       "tm_plate": "#94A3B8", "converter": "#16A34A", "breakaway": "#FACC15", "tether": "#F59E0B"}

_C = {}


def C(key, payload="float"):
    k = (key, payload)
    if k not in _C:
        comps = M.build_components(P, payload)
        for kk, c in comps.items():
            _C[(kk, payload)] = c.shape
    return _C[k]


def part(key, shape=None, explode=(0, 0, 0), name=None, payload="float"):
    return Part(name or M.BOM[key][1], C(key, payload) if shape is None else shape, COL[key], None, tuple(explode))


def ghost(name, shape):
    return Part(name, shape, "#D1D5DB")


RIGHT = (0.797, 0.498)                         # screen-right for the default camera (20 deg, -58 deg)


def side(k, dz):
    """Offset that moves a part to the right of the hub stack in the overview, then up by dz."""
    return (RIGHT[0] * k, RIGHT[1] * k, dz)


def out(vec_r, dz=0.0):
    """Explode vector along the front-right arm (outward by vec_r) plus dz."""
    return (U[0] * vec_r, U[1] * vec_r, dz)


# single arm, placed (world frame) and local (arm along +X)
LOC = M.arm_group_local(P)
LOC_HB = M.hinge_block_local(P)
LOC_PIV = M.pivot_pin_local(P)
LOC_LCK = M.lock_pin_local(P)


def arm1(key):
    src = {"hinge_blocks": LOC_HB, "pivots": LOC_PIV, "lock_pins": LOC_LCK}
    return turn(src.get(key, LOC.get(key)), ARM)


def crop(shape, *b):
    return shape & bx(*b)


# ----------------------------------------------------------------- overview
def overview():
    zb = P["z_bot"]
    hub = [
        ("Bottom hub plate", C("bot_plate"), "bot_plate", (0, 0, 0)),
        ("Arm hinge blocks (4), one shown", arm1("hinge_blocks"), "hinge_blocks", side(250, 60)),
        ("Hub spacers and deck standoffs (8)", C("spacers"), "spacers", (0, 0, 250)),
        ("Kitewright Core (Core), hung under the hub", C("core"), "core", (0, 0, -150)),
        ("Top hub plate", C("top_plate"), "top_plate", (0, 0, 330)),
        ("Gear top blocks (4)", C("gear_tops"), "gear_tops", (0, 0, -220)),
        ("Gear struts (4)", C("struts"), "struts", (0, 0, -330)),
        ("Skid blocks (4)", C("skid_blocks"), "skid_blocks", (0, 0, -440)),
        ("Skids (2)", C("skids"), "skids", (0, 0, -500)),
        ("Core rail, locking pins and pigtail (Core)", C("rails") + C("ds014") + C("paylock"), "rails", (0, 0, -260)),
        ("Arm tubes (4), one shown", arm1("arm_tubes"), "arm_tubes", side(650, 330)),
        ("Arm root fittings (4), one shown", arm1("arm_roots"), "arm_roots", side(500, 330)),
        ("Motor mounts (4), one shown", arm1("motor_mounts"), "motor_mounts", side(800, 330)),
        ("Motors (8), two shown", arm1("motors"), "motors", side(950, 330)),
        ("Motor controllers (8), two shown", arm1("escs"), "escs", side(650, 520)),
        ("Pivot bolt and lock pin (4 each), one shown", arm1("pivots") + arm1("lock_pins"), "lock_pins", side(350, 200)),
        ("Folding propellers (8), two shown", arm1("props"), "props", side(1100, 600)),
        ("Battery deck", C("deck"), "deck", (0, 0, 440)),
        ("Pack guides (2)", C("guides"), "guides", (0, 0, 540)),
        ("GNSS mast", C("mast"), "mast", (0, 0, 800)),
        ("ColdCell packs (2) and straps (4)", C("packs") + C("straps"), "packs", (0, 0, 640)),
        ("Float release payload", C("fr_plate") + C("saddles") + C("release") + C("sling") + C("float"), "float", (-300, -800, -450)),
        ("Tether module payload", Pos(-900, 650, 0) * (C("tm_plate", "tether") + C("converter", "tether") + C("breakaway", "tether")),
         "converter", (0, 0, -300)),
    ]
    parts = [Part(n, s, COL[k], None, tuple(e)) for n, s, k, e in hub]
    bv.overview(parts, OUT / "overview.png", "Kitewright Lift prototype: every component in build order",
                subtitle="Hub stack and gear first, the Core under the hub, then the arms (one of four shown), deck, packs and payloads",
                key=True, size=(12, 8.5), elev=20)


# ----------------------------------------------------------------- making sketches
REV_P2 = {  # sheets changed by Amish's decision 34A of 2026-10-03 (KWL-DDR-003)
    "KWL-DWG-104": "KWL-DDR-003: side pockets, cheek window and cuts",
    "KWL-DWG-105": "KWL-DDR-003: tongue side pockets, taller window",
    "KWL-DWG-106": "KWL-DDR-003: tube 405 long for the shorter clamp",
    "KWL-DWG-107": "KWL-DDR-003: clamp shortened to 40",
}
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

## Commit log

2026-10-03 Kitewright Lift at TRL 3: constructable design (kit 1.7.0)
    Problem, concept and requirements; sizing calculations; CAD model, STEP and STL; general arrangement drawing; bill of materials; build plan with making sketches, joint close-ups and step pictures; design decisions register (design choices decided under Amish's 2026-10-03 pre-approval; requirement decisions open for Amish); TRL 2 and TRL 3 review; photoreal renders and storefront card. Private until Amish opens it.
    [bom.csv, kitewright-lift-arm-root-fitting.step, kitewright-lift-arm-root-fitting.stl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]
2026-10-04 Carry Amish's round 2 requirement decisions into the design
    Amish approved all 47 recommendations on 2026-10-03 ("i approve all of the 47 recommendations provided by you. Execute them."). Each repo gains a decision record (DDR-003, or the next free number for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
    [bom.csv, kitewright-lift-arm-root-fitting.step, kitewright-lift-arm-root-fitting.stl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]
2026-10-04 Carry Amish's round-2 and round-3 decisions into the design
    Amish approved all 46 round-2 recommendations ("i agree with all the 46 recommendations you provided. please proceed.") and all round-3 recommendations ("For round 3, I agree with all your proposed r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
    [bom.csv, kitewright-lift-arm-root-fitting.step, kitewright-lift-arm-root-fitting.stl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]

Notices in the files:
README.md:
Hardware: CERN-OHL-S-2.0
